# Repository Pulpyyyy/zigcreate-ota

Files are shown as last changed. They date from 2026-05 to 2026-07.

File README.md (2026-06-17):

# ZigCreate OTA — Bridge Zigbee pour ventilateur de plafond

Transformez votre ventilateur Tuya en appareil Zigbee natif, pilotable depuis votre box domotique favorite.

---

## Ce que vous pouvez contrôler

| Fonction | Contrôles disponibles |
|---|---|
| **Ventilateur** | Marche/arrêt · 6 niveaux de vitesse |
| **Lumière** | Marche/arrêt · Température de couleur en **cycle** (cran suivant : Froid→Neutre→Chaud→…) |
| **Minuterie** | Préréglages `1h` / `2h` / `4h` · Décompte visible en temps réel · Réinitialisation automatique à `off` en fin de décompte |
| **Son** | Activation / désactivation du bip de confirmation |
| **Direction** | Mode Été (brassage vers le bas) · Mode Hiver (remontée d'air chaud) |
| **Comportement après coupure** | État de la lumière et du son configurables (éteint / allumé / bascule / restauration) |
| **Température / Humidité** | Lecture de la température et de l'humidité ambiante — nécessite un capteur DHT11/DHT22 (optionnel, voir [câblage](wiring/WIRING.md#capteur-de-température--humidité-optionnel)) |

---

## Fonctionnalités

### Contrôle complet depuis l'interface domotique

Toutes les commandes sont disponibles depuis Zigbee2MQTT ou toute box compatible Zigbee :

- **Ventilateur** — marche/arrêt indépendant de la vitesse ; la vitesse peut être réglée de 1 à 6 sans éteindre le ventilateur. La dernière vitesse est mémorisée et restaurée à la prochaine mise en marche.
- **Lumière** — marche/arrêt avec mémorisation de l'état. **Température de couleur : cycle uniquement** — le matériel ne permet pas de choisir une couleur absolue, on ne peut qu'avancer d'un cran (Froid→Neutre→Chaud→…) comme avec la télécommande. La valeur remontée par le MCU est découplée de la couleur réelle, donc aucun état couleur fiable n'est exposé.
- **Minuterie** — déclenche l'extinction automatique après 1 h, 2 h ou 4 h. Le décompte restant (en minutes) est visible en temps réel dans l'interface. Le préréglage repasse automatiquement à `off` lorsque le décompte atteint zéro.
- **Son (bip)** — active ou désactive le bip sonore émis par l'appareil lors de chaque commande.
- **Direction** — inverse le sens de rotation du ventilateur pour le mode Hiver.

### Synchronisation en temps réel

Utiliser la télécommande physique (vitesse, on/off, direction…) met à jour l'état dans l'interface domotique instantanément. L'état est également resynchronisé automatiquement à chaque redémarrage du module.

### Comportement après coupure de courant

Il est possible de définir ce que fait chaque appareil au redémarrage après une coupure de courant. Ce réglage est disponible séparément pour la **lumière** et le **son** :

| Valeur | Comportement |
|---|---|
| `off` | Toujours éteint au démarrage |
| `on` | Toujours allumé au démarrage |
| `toggle` | Inverse l'état précédent |
| `previous` (défaut lumière) | Restaure l'état avant la coupure |

La température de couleur n'est PAS restaurée (cycle uniquement / découplée — voir ci-dessus). Par défaut, le bip démarre toujours désactivé.

### Mises à jour sans fil (OTA)

Le firmware se met à jour par liaison radio depuis Zigbee2MQTT, sans démontage ni câble. Les mises à jour sont proposées automatiquement dès qu'une nouvelle version est disponible dans l'index OTA de ce dépôt.

### Rôle routeur Zigbee

Le module fonctionne en tant que **routeur Zigbee** : il peut relayer les communications d'autres appareils Zigbee du réseau, contribuant ainsi à améliorer la portée et la robustesse du maillage.

### Indicateur LED

La LED RGB intégrée indique l'état du module en temps réel :

| Couleur / comportement | Signification |
|---|---|
| 🟠 Orange (ramping) | Démarrage en cours |
| 🔵 Cyan clignotant (0,5 s) | Recherche d'un réseau Zigbee (appairage) |
| 🟢 3 flashes verts | Appairage réussi |
| 🔴 Rouge clignotant rapide | Échec de connexion, nouvelle tentative |
| 🟡 Ambre (1 s on / 2 s off) | Mode dégradé — MU ventilateur injoignable |
| 🟠 Orange clignotant | Réinitialisation en attente (bouton maintenu) |
| ⚫ Éteinte | Fonctionnement normal |

### Réinitialisation

- **Bouton BOOT (5 s)** — maintenir le bouton BOOT appuyé 5 secondes remet l'appareil en configuration d'usine : effacement du réseau Zigbee mémorisé, des préférences et de l'historique de diagnostics. L'appareil redémarre ensuite en mode appairage.
- **GPIO externe** — un signal bas sur le GPIO de reset externe provoque un redémarrage simple (sans effacement). Consultez le [guide de câblage](wiring/WIRING.md).

### Récupération automatique

Si la connexion Zigbee échoue 3 fois de suite au démarrage, le module efface automatiquement sa configuration réseau corrompue et redémarre proprement.

Si le ventilateur ne répond plus pendant 15 secondes, le module passe en mode dégradé (LED ambre) : les commandes sont suspendues jusqu'au rétablissement de la communication, puis le fonctionnement reprend automatiquement.

---

## Câblage

Consultez le guide de câblage pour connaître les GPIOs à connecter selon votre carte :

- [Pinout Waveshare ESP32-H2-Zero](wiring/WIRING.md#waveshare-esp32-h2-zero)

---

## Installation dans Zigbee2MQTT

Le converter externe expose toutes les entités de l'appareil dans Z2M : ventilateur, lumière, minuterie, bip, direction, température de couleur, et capteurs de température / humidité.

**[→ Guide d'installation Z2M complet](../external_converters/README.md)**

---

## Installation dans ZHA (Home Assistant)

Le quirk custom permet à ZHA de reconnaître l'appareil et d'exposer les entités natives Home Assistant.

**[→ Guide d'installation ZHA complet](../zha_quirks/README.md)**

---

## Dépannage

En cas de problème en fonctionnement (LED ambre, commandes sans effet, bootloop, capteur DHT muet…), consultez le guide dédié :

**[→ Guide de dépannage](TROUBLESHOOTING.md)**

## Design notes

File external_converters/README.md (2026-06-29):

# Installation du converter Zigbee2MQTT

> Un **converter** est un fichier qui indique à Zigbee2MQTT comment communiquer avec l'appareil et quelles entités exposer.

---

## 1. Copier le converter

L'emplacement du dossier `external_converters/` dépend de votre installation Z2M :

| Installation | Chemin |
|---|---|
| **Add-on HA** | même dossier que `configuration.yaml` (ex. `/config/zigbee2mqtt/external_converters/`) |
| **LXC / Docker** | `data/external_converters/` dans le répertoire de données Z2M |

Créez le dossier s'il n'existe pas et copiez-y `create_wind_calm.mjs`.

---

## 2. Déclarer le converter

### Option A — via l'interface Z2M

Dans Z2M → **Paramètres** → **External converters**, ajoutez `create_wind_calm.mjs` directement depuis l'UI.

### Option B — via `configuration.yaml`

Ajoutez dans `configuration.yaml` :

```yaml
advanced:
  enable_external_js: true

external_converters:
  - create_wind_calm.mjs
```

Redémarrez Zigbee2MQTT. L'appareil **WIND-CALM (CREATE)** sera reconnu automatiquement lors du prochain appairage.

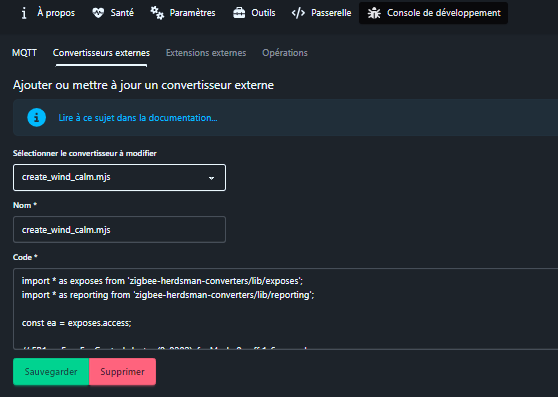
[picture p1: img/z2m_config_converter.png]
Converter déclaré dans configuration.yaml


---

## 3. Ajouter l'icône de l'appareil

Copiez le fichier `device_icons/windcalm.png` dans le dossier `images/devices/` au même niveau que `configuration.yaml` (créez le dossier s'il n'existe pas).

Ajoutez ensuite l'entrée dans votre `configuration.yaml` :

```yaml
devices:
  '0x<ieee_address>':
    friendly_name: wind_calm
    icon: 'images/devices/windcalm.png'
```

> Remplacez `0x<ieee_address>` par l'adresse IEEE réelle de votre appareil, visible dans l'interface Zigbee2MQTT après appairage.

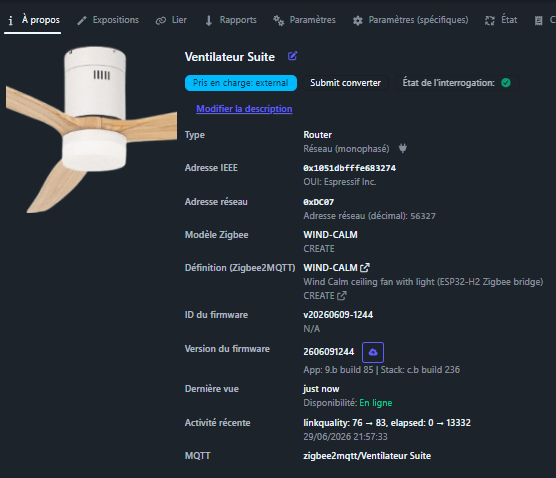
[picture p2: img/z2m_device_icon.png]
Appareil avec icône dans la liste des appareils Z2M


---

## 4. Activer les mises à jour OTA

```yaml
ota:
  zigbee_ota_override_index_location: https://raw.githubusercontent.com/Pulpyyyy/zigcreate-ota/main/ota/index.json
```

Redémarrez Zigbee2MQTT. Les mises à jour firmware seront proposées automatiquement.

Mise à jour OTA disponible dans Z2M

---

## 5. Appairer l'appareil

Activez le mode appairage dans Zigbee2MQTT, puis mettez le module sous tension (ou maintenez BOOT 5 s pour réinitialiser).

La LED clignote en **cyan** pendant la recherche de réseau, puis effectue **3 flashes verts** à la réussite.

---

## Entités disponibles

| Entité | Type | Description |
|---|---|---|
| `fan` | Interrupteur | Marche / arrêt du ventilateur |
| `fan_mode` | Liste | Vitesse du ventilateur (1 à 6) |
| `light` | Interrupteur | Marche / arrêt de la lumière |
| `color_step` | Interrupteur momentané | Température de couleur — **cycle uniquement** : passer sur **ON** avance d'un cran (froid→neutre→chaud→…) puis revient à **OFF** automatiquement. Cette ampoule ne permet PAS de choisir une couleur absolue, et il n'y a pas d'état couleur fiable. |
| `timer_preset` | Liste | Minuterie : `off` / `1h` / `2h` / `4h` |
| `timer_countdown` | Capteur | Décompte restant en minutes (lecture seule) |
| `beep` | Interrupteur | Bip sonore actif / silencieux |
| `direction` | Liste | Sens de rotation : `forward` (été) / `reverse` (hiver) |
| `power_on_behavior_light` | Liste | Comportement lumière après coupure |
| `power_on_behavior_beep` | Liste | Comportement bip après coupure |
| `temperature` | Capteur | Température ambiante (°C) — **désactivée par défaut** · requiert un capteur DHT11/DHT22 |
| `humidity` | Capteur | Humidité relative (%) — **désactivée par défaut** · requiert un capteur DHT11/DHT22 |
| `debug_firmware` | Interrupteur (config) | Bascule OTA du firmware : `ON` = build debug, `OFF` = build release. L'appareil persiste le choix, redémarre et télécharge l'image du canal correspondant. Outil de maintenance/dev. |

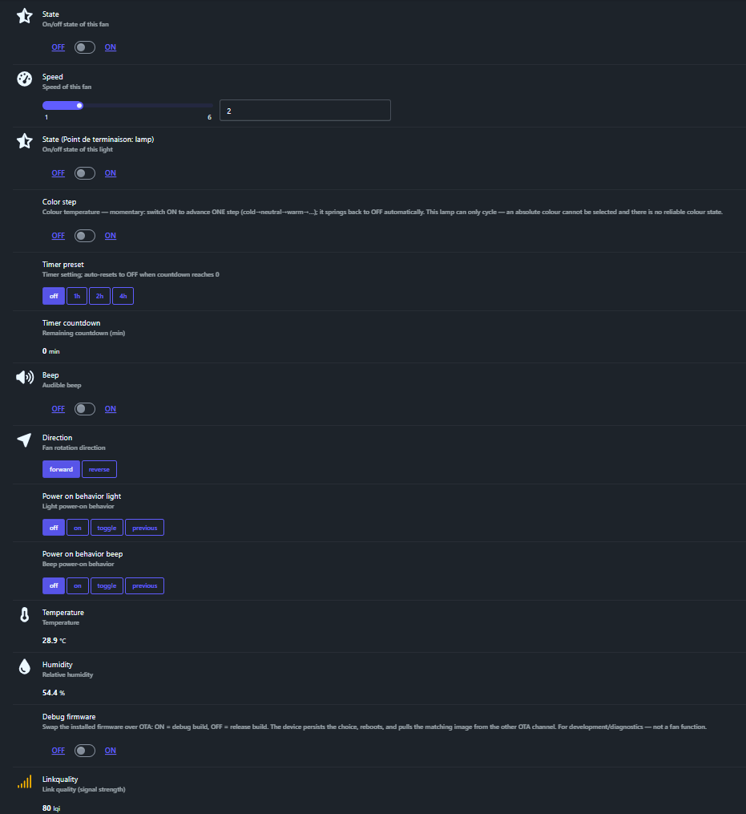
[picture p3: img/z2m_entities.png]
Toutes les entités dans l'interface Z2M


> Les entités `temperature` et `humidity` nécessitent un capteur DHT11/DHT22 câblé sur le module (voir [câblage](../docs/wiring/WIRING.md#capteur-de-température--humidité-optionnel)).
>
> L'interrupteur `debug_firmware` permet de passer un appareil déployé du firmware release au firmware debug (et inversement) **entièrement par OTA**, sans repasser par l'USB. Les deux canaux (release / debug) sont publiés automatiquement par la CI ; basculer l'interrupteur fait que l'appareil réclame l'image de l'autre canal au prochain cycle OTA.

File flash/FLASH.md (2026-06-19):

# Flasher le ZigCreate (ESP32-H2) via navigateur

Ce guide explique comment flasher le firmware **ZigCreate** sur une carte ESP32-H2 en utilisant l'outil en ligne **esptool-js**, sans installer de logiciel.

---

## Prérequis

- **Navigateur** : Google Chrome ou Microsoft Edge (WebSerial requis — Firefox non supporté)
- **Câble** : USB-C (données, pas uniquement charge)
- **Drivers** : Si votre carte utilise un chip USB-UART (CP2102, CH340…), installez le driver correspondant. Les cartes avec USB natif ESP32-H2 (ex : Waveshare ESP32-H2-Zero) n'en ont pas besoin.

---

## 1. Télécharger les binaires

Rendez-vous sur la dernière release du dépôt OTA :

> **https://github.com/Pulpyyyy/zigcreate-ota/releases/latest**

Téléchargez ces quatre fichiers :

| Fichier | Rôle |
|---|---|
| `bootloader.bin` | Bootloader ESP32-H2 |
| `partition-table.bin` | Table de partitions |
| `ota_data_initial.bin` | Indique au bootloader la partition à démarrer (optionnel, utilisé pour debug OTA)|
| `zigcreate.bin` | Firmware applicatif |

> `zigcreate.ota` est réservé aux mises à jour Zigbee over-the-air — **ne pas utiliser ici**.

---

## 2. Passer l'ESP32-H2 en mode téléchargement (Download Mode)

1. Maintenez le bouton **BOOT** (GPIO9) enfoncé
2. Appuyez brièvement sur **RESET** (bouton EN ou broche EN à la masse), puis relâchez-le
3. Relâchez le bouton **BOOT**

La carte est maintenant en mode téléchargement et attend un flash.

> Sur certaines cartes sans bouton dédié, le mode download s'active en maintenant GPIO9 à la masse au démarrage.

---

## 3. Flasher avec esptool-js

### 3.1 Ouvrir l'outil

Accédez à : **https://espressif.github.io/esptool-js/**

### 3.2 Se connecter

1. Cliquez sur **Connect**
2. Sélectionnez le port série correspondant à votre carte (ex : `COM3`, `COM8`, `/dev/ttyUSB0`)
3. Cliquez sur **Connect** dans la boîte de dialogue du navigateur

### 3.3 Configurer le flash

Dans la section **Flash Address**, renseignez les quatre fichiers avec leurs adresses exactes :

| Fichier | Adresse flash |
|---|---|
| `bootloader.bin` | `0x0` |
| `partition-table.bin` | `0x8000` |
| `ota_data_initial.bin` | `0x10000` |
| `zigcreate.bin` | `0x30000` |

Pour ajouter un fichier supplémentaire, cliquez sur **Add File**.

> Ces adresses correspondent à la table de partitions du projet. Ne pas les modifier.

### 3.4 Paramètres

| Paramètre | Valeur |
|---|---|
| Flash mode | `keep` |
| Flash frequency | `keep` |
| Flash size | `keep` |

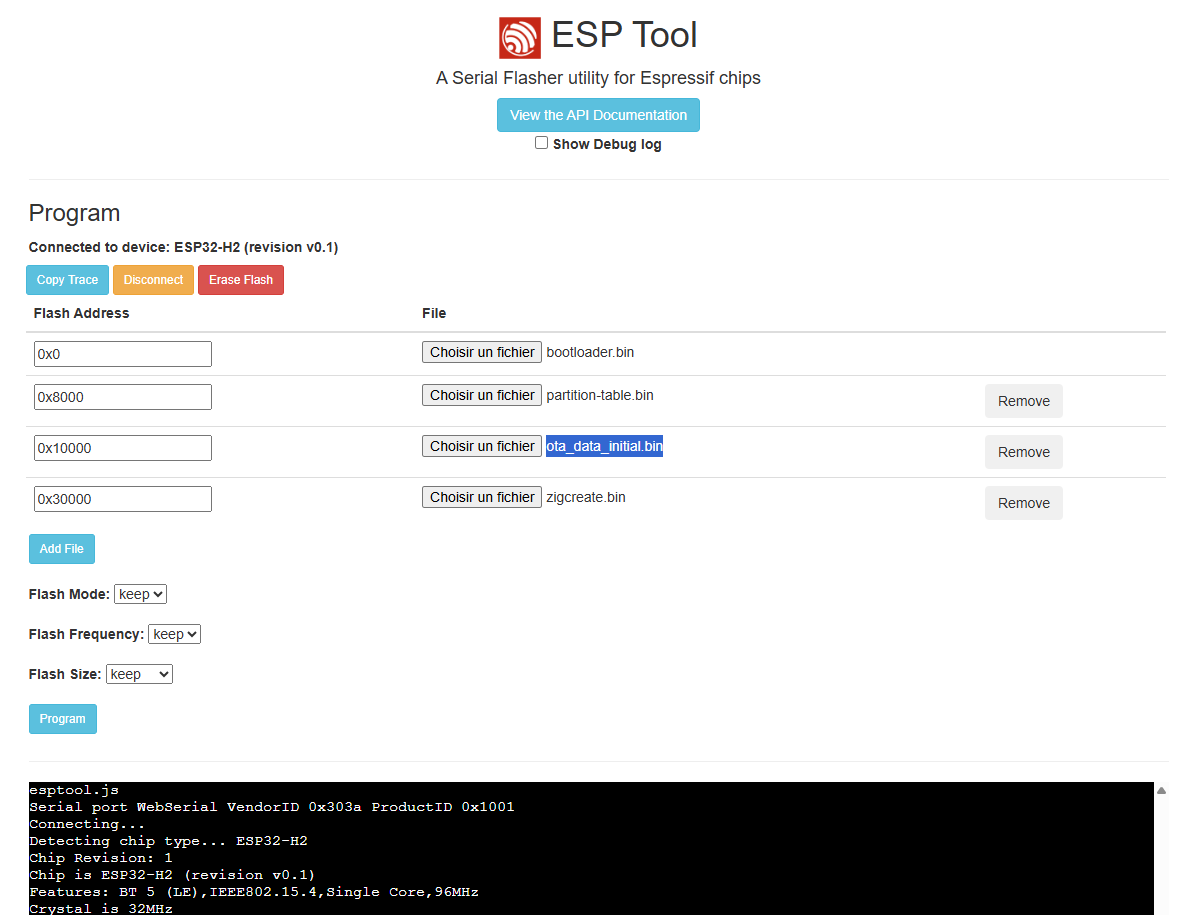
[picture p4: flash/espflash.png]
Configuration esptool-js


### 3.5 Lancer le flash

1. Cliquez sur **Program**
2. Attendez la fin du processus (la progression s'affiche dans la console)
3. Le message `Leaving... Hard resetting via RTS pin...` indique que le flash est terminé avec succès

---

## 4. Vérification

Après le flash, la carte redémarre automatiquement. La séquence LED normale est :

1. **Orange** (quelques secondes) — initialisation du module
2. **Cyan clignotant** — le module cherche un réseau Zigbee (appairage en cours)

> Le cyan clignotant est normal si aucun coordinateur Zigbee n'est à portée. L'appairage se fait depuis votre box domotique.

Si la carte ne redémarre pas, appuyez manuellement sur **RESET** (bouton EN ou broche EN à la masse brièvement).

---

## Résumé des adresses

```
0x00000  bootloader.bin
0x08000  partition-table.bin
0x10000  ota_data_initial.bin
0x30000  zigcreate.bin
```

---

## Dépannage

| Problème | Solution |
|---|---|
| Port non visible dans le navigateur | Vérifier le driver USB-UART, essayer un autre câble |
| Erreur de connexion | Recommencer la procédure mode téléchargement (étape 2) |
| La carte ne démarre pas après flash | Vérifier que les quatre fichiers sont bien flashés aux bonnes adresses |
| `Failed to connect` | S'assurer qu'aucun autre programme (moniteur série, IDE) n'occupe le port |

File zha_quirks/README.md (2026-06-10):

# Installation du quirk ZHA (Home Assistant)

> **ZHA** est l'intégration Zigbee native de Home Assistant.
> Un **quirk** est un fichier de personnalisation qui permet à ZHA de reconnaître correctement un appareil non standard. C'est l'équivalent du converter pour Zigbee2MQTT.

---

## 1. Copier le quirk

Copiez le fichier `create_wind_calm.py` dans le dossier `/config/custom_zha_quirks/` de votre installation Home Assistant (créez le dossier s'il n'existe pas).

```
config/
└── custom_zha_quirks/
    └── create_wind_calm.py
```

Quirk copié dans le dossier custom_zha_quirks via l'éditeur de fichiers HA

---

## 2. Déclarer le dossier de quirks dans configuration.yaml

```yaml
zha:
  custom_quirks_path: /config/custom_zha_quirks
```

Entrée zha dans configuration.yaml

---

## 3. Réappairer l'appareil

Redémarrez Home Assistant, puis réappairez l'appareil **WIND-CALM (CREATE)**.

Activez le mode appairage ZHA depuis **Paramètres → Appareils et services → ZHA → Ajouter un appareil**, puis mettez le module sous tension (ou maintenez BOOT 5 s pour réinitialiser).

La LED clignote en **cyan** pendant la recherche de réseau, puis effectue **3 flashes verts** à la réussite.

Appareil WIND-CALM reconnu lors de l'appairage ZHA

---

## Entités disponibles

| Fonction | Type d'entité HA | Description |
|---|---|---|
| Ventilateur | Ventilateur natif | Marche/arrêt + vitesse 1 à 6 |
| Lumière | Lumière | Marche/arrêt |
| Couleur (`color_step`) | Bouton | Température de couleur — **cycle uniquement** : chaque appui avance d'un cran (Froid→Neutre→Chaud→…). Pas de choix absolu possible. |
| Minuterie | — | Pas d'entité ZHA native — disponible uniquement via Zigbee2MQTT |
| Bip sonore | Interrupteur | Activation / désactivation du bip |
| Direction | Interrupteur | Éteint = été (brassage vers le bas) · Allumé = hiver (remontée d'air) |
| Température | Capteur | Température ambiante (°C) — requiert un capteur DHT11/DHT22 |
| Humidité | Capteur | Humidité relative (%) — requiert un capteur DHT11/DHT22 |
| Firmware debug | Interrupteur | Bascule OTA release ⇄ debug (Éteint = release, Allumé = debug) ; l'appareil redémarre et télécharge l'image correspondante. Maintenance/dev. |

Page de l'appareil dans Home Assistant avec toutes ses entités

---

## Limitations vs Zigbee2MQTT

- **Température de couleur** : **cycle uniquement.** Le matériel ne permet PAS de choisir une couleur absolue — le MCU ne fait que cycler la couleur par paliers (Froid→Neutre→Chaud→…), comme la télécommande, et la valeur qu'il remonte est découplée de la couleur réelle. L'entité `color_step` est donc un simple **bouton** « cran suivant » (chaque appui = un cran), sans état fiable.
- **Minuterie** : non accessible directement dans ZHA. Pour l'utiliser, passez par **Zigbee2MQTT** ou créez une automatisation HA avancée via le service `zha.issue_zigbee_cluster_command`.
- **Mises à jour OTA** : les mises à jour sans fil via ZHA ne sont pas supportées. Utilisez Zigbee2MQTT pour les OTA.

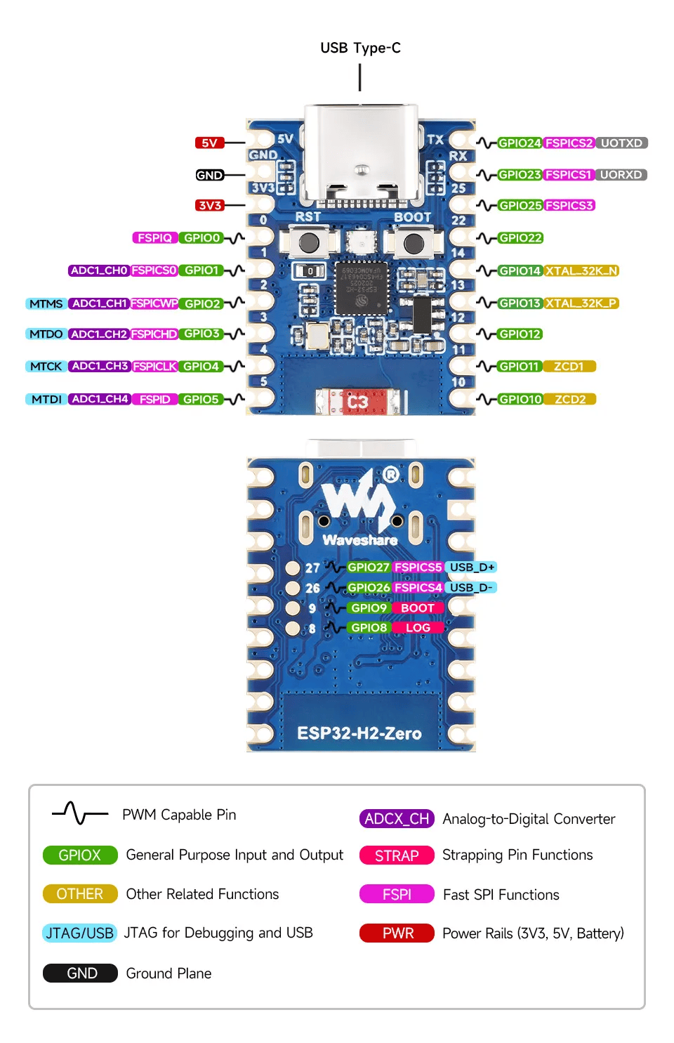
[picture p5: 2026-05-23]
pcb/H2 zero/pinout top bottom.png

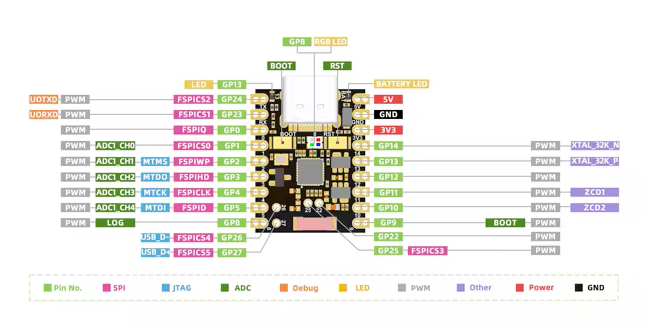
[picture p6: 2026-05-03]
pcb/H2 supermini/ESP32 pinout.png

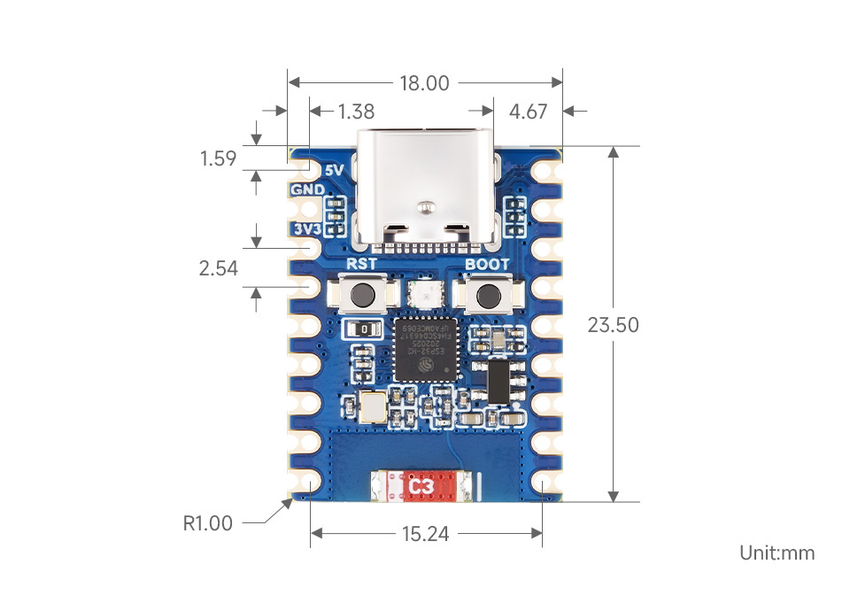
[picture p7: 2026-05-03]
pcb/H2 supermini/ESP32 size.jpg

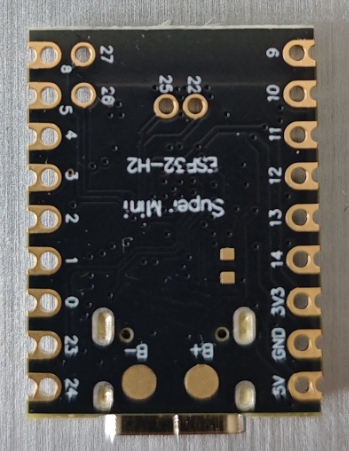
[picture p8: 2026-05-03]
pcb/H2 supermini/dessous.jpg

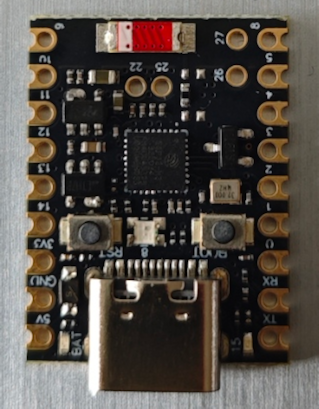
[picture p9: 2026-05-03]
pcb/H2 supermini/dessus.png

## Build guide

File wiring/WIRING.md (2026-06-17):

# Câblage ZigCreate — Pinout par carte

Ce guide décrit les connexions à réaliser entre l'ESP32-H2 et le MCU Tuya du ventilateur, selon la carte utilisée.

---

## Alimentation — point critique

Le MCU Tuya expose une sortie **3,3 V** qui sert à alimenter l'ESP32-H2-Zero via sa broche **3V3**. Ne jamais alimenter l'ESP32-H2 simultanément via USB et via cette broche — risque de conflit d'alimentation.

> **Carte recommandée : Waveshare ESP32-H2-Zero.** Alimentée en 3,3 V depuis le MCU Tuya, elle fonctionne de façon stable.
>
> ⚠️ **L'ESP32-H2 Super Mini est à éviter** : son régulateur interne provoque un *bootloop* (redémarrages en boucle) lors de l'alimentation directe, malgré l'ajout de condensateurs de découplage (10 µF à 470 µF testés). Cette piste a été abandonnée.

---

## Connexions à réaliser (toutes cartes)

| Signal | De | Vers | Remarque |
|---|---|---|---|
| VCC | MCU Tuya — 3,3 V | ESP32-H2 — broche **3V3** | Alimentation directe |
| GND | MCU Tuya — GND | ESP32-H2 — GND | Masse commune obligatoire |
| TX | ESP32-H2 — GPIO TX | MCU Tuya — RX | |
| RX | MCU Tuya — TX | ESP32-H2 — GPIO RX | |

> La liaison UART fonctionne en **8N1 à 9600 baud**. TX de l'ESP32 → RX du MCU Tuya, et inversement.

---

## Waveshare ESP32-H2-Zero

```
En-têtes de la carte (vue de dessus, USB-C en haut) :

En-tête gauche (haut → bas)   En-tête droit (haut → bas)
  5V                              24 (TX)
  GND  ─── Masse commune         23 (RX)
  3V3  ◄── VCC depuis MCU         25
  0                              22
  1                              14
  2    ◄── EXT_RESET             13
  3    ◄── DHTxx DATA             12
  4    ──► TUYA TX               11
  5    ◄── TUYA RX               10
```

| Fonction | GPIO | Broche en-tête | Remarque |
|---|---|---|---|
| UART TX → MCU Tuya RX | GPIO4 | En-tête gauche, 8e | |
| UART RX ← MCU Tuya TX | GPIO5 | En-tête gauche, 9e | |
| Alimentation entrée | — | En-tête gauche, 3e (**3V3**) | Depuis le 3,3 V du MCU Tuya |
| Masse | — | En-tête gauche, 2e (**GND**) | Commune avec MCU Tuya |
| LED RGB (WS2812) | GPIO8 | Pad LOG (castellé) | Interne, ne pas câbler |
| Bouton BOOT / Reset Zigbee | GPIO9 | Pad castellé bas | En fonctionnement normal : maintenir 5 s pour reset usine. Pour le flash : voir [FLASH.md](../flash/FLASH.md) |
| Reset externe (actif bas) | GPIO2 | En-tête gauche, 6e | Redémarrage software |
| Capteur T°/HR DATA (optionnel) | GPIO3 | En-tête gauche, 7e | Voir section [Capteur T°/HR](#capteur-de-température--humidité-optionnel) |
| USB D+ | GPIO27 | Pad castellé bas | Réservé USB, ne pas utiliser |
| USB D- | GPIO26 | Pad castellé bas | Réservé USB, ne pas utiliser |

### Schéma de câblage

```
Waveshare ESP32-H2-Zero          MCU Tuya
┌──────────────────┐            ┌──────────┐
│  3V3         ◄───┼────────────│ 3V3      │
│  GND         ────┼────────────│ GND      │
│  GPIO4  (TX) ────┼────────────│ RX       │
│  GPIO5  (RX) ◄───┼────────────│ TX       │
│  GPIO2 (RST) ◄───┼────────────│ EN       │
└──────────────────┘            └──────────┘
```

### Photos du câblage

ESP32-H2-Zero avec les connecteurs Dupont :

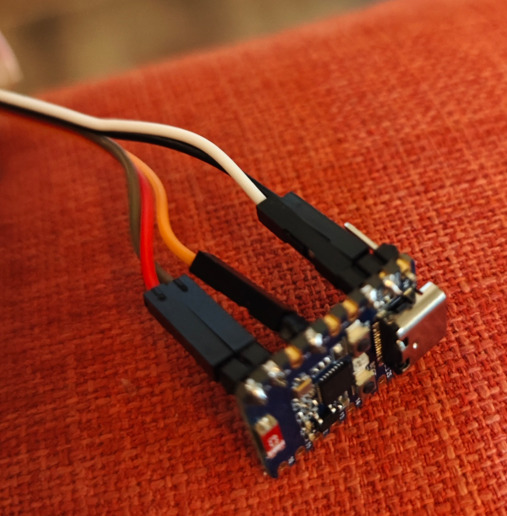
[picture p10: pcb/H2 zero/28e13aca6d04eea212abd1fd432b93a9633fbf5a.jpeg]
ESP32-H2-Zero câblé


MCU Tuya côté ventilateur :

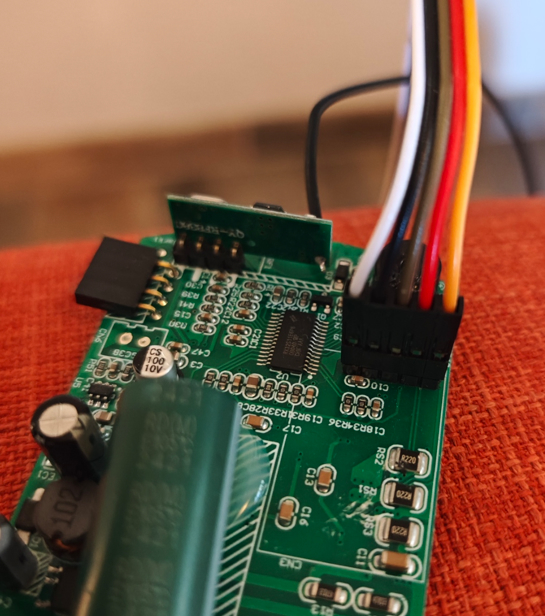
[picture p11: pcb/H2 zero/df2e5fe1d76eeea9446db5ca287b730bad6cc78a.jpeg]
MCU Tuya câblé


---

## Préparation & test à blanc avant soudure définitive

> **Toujours valider en Dupont/USB avant de souder en permanence.** Une fois la carte soudée dans le plafonnier, reprendre un TX/RX inversé devient pénible. Le câblage Dupont (photos ci-dessus) sert précisément à cette phase de validation.

1. **Flasher + appairer la carte d'abord sur USB**, hors ventilateur. Vérifier la séquence LED orange → cyan clignotant → 3 flashes verts, et que l'appareil apparaît dans Zigbee2MQTT / ZHA. → firmware et radio validés avant tout câblage.
2. **Repérer les 4 points sur le MCU Tuya** : 3,3 V, GND, MCU-TX, MCU-RX.
3. **Câbler en Dupont** : 3V3↔3V3, GND↔GND, **ESP TX (GPIO4) → MCU RX**, **MCU TX → ESP RX (GPIO5)**. L'inversion TX/RX est l'erreur la plus fréquente.
4. **Ne jamais alimenter en USB *et* en 3,3 V simultanément.** Pour ce test : soit USB seul, soit 3,3 V du MCU seul.
5. **Test fonctionnel complet en Dupont** : ventilateur (6 vitesses), lumière, cycle de couleur, minuterie, direction, bip — et la **synchro télécommande** (agir sur la télécommande physique doit mettre à jour l'état dans l'interface). Si la LED passe **ambre**, le MCU ne répond pas → voir le [guide de dépannage](../TROUBLESHOOTING.md).
6. **Capteur DHT (optionnel)** : vérifier que température et humidité remontent **avant** de souder. Alimentation **3,3 V** (jamais 5 V).
7. **Vérifier l'orientation de la carte et le dégagement de l'antenne** dans le boîtier avant de figer : l'antenne Zigbee ne doit pas être plaquée contre une masse métallique.
8. **Souder définitivement** une fois tout validé, puis effectuer un dernier test fonctionnel.

---

## Reset externe (optionnel)

Un niveau bas (GND) bref sur ce GPIO provoque un redémarrage software, sans effacer le réseau Zigbee ni les préférences.

| Carte | GPIO | Broche en-tête |
|---|---|---|
| ESP32-H2-Zero | GPIO2 | En-tête gauche, 6e |

> Pour un reset usine complet (effacement réseau + préférences), utiliser le bouton BOOT maintenu **5 secondes**.

---

## Capteur de température / humidité (optionnel)

Le firmware intègre la prise en charge d'un capteur **DHT22** ou **DHT11** pour reporter la température et l'humidité ambiantes via Zigbee. Ce capteur est **entièrement optionnel** : sans lui, toutes les autres fonctions restent opérationnelles.

> **DHT11 ou DHT22 ?** Le câblage est identique (même protocole 1 fil) et le firmware **détecte automatiquement** le capteur branché (DHT22, DHT11 ou aucun) — rien à configurer. Au démarrage il sonde les deux familles et verrouille celle qui répond ; si aucun capteur n'est présent, la tâche se contente d'avertir sans perturber le reste. Le DHT22 est plus précis et couvre les températures négatives ; le DHT11 est moins cher mais limité (0–50 °C, ±2 °C, ±5 % HR, résolution 1°).

### Module PCB recommandé

> Utiliser de préférence un **module sur PCB** (3 broches : VCC, DATA, GND). Ces modules intègrent la résistance de pull-up et le condensateur de découplage — aucun composant externe à ajouter.
>
> Le capteur nu (4 broches) nécessite l'ajout d'une résistance de 4,7 kΩ à 10 kΩ entre VCC et DATA, et d'un condensateur 100 nF entre VCC et GND.

Module DHT22 sur PCB (3 broches) tout intégré, câble direct :

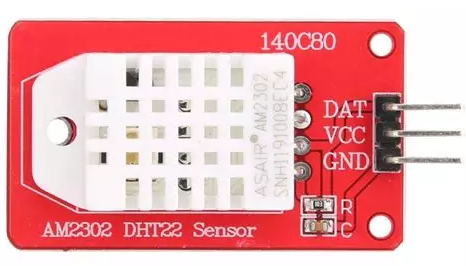
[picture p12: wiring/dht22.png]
Module DHT22 sur PCB


### Connexions

| Signal | Module capteur | ESP32-H2 | Remarque |
|---|---|---|---|
| VCC | VCC | **3,3 V** | Ne pas alimenter en 5 V |
| GND | GND | GND | Masse commune |
| DATA | DATA | GPIO selon carte | Voir tableau ci-dessous |

| Carte | GPIO DATA capteur | Broche en-tête |
|---|---|---|
| ESP32-H2-Zero | GPIO3 | En-tête gauche, 7e |

### Entités Zigbee générées

Une fois câblé, le firmware reporte automatiquement la température et l'humidité toutes les 60 secondes :

| Entité | Cluster ZCL | Précision |
|---|---|---|
| `temperature` | TemperatureMeasurement (0x0402) | 0,1 °C |
| `humidity` | RelativeHumidity (0x0405) | 0,1 % |

> Sous **Zigbee2MQTT**, ces entités sont **désactivées par défaut** — les activer manuellement dans l'interface HA si souhaité.
> Sous **ZHA**, les entités température et humidité sont créées actives.

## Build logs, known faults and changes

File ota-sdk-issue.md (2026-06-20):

# [Bug] OTA Upgrade client silently resets the download to FileOffset=0 on a single ImageBlockResponse timeout (no block retry, no ABORT callback)

## Environment

| | |
|---|---|
| **esp-zigbee-lib** | `2.0.1` (dependency `espressif/esp-zigbee-lib: ~2.0.0`) |
| **ESP-IDF** | `v6.0.1` |
| **Chip** | ESP32-H2 (rev v1.2), native 802.15.4 radio |
| **Device role** | Router, ZCL OTA Upgrade **client** (cluster 0x0019) |
| **OTA coordinator/server** | Zigbee2MQTT (zigbee-herdsman 10.4.0) |
| **Requested block size** | 255 B via `ezb_zcl_ota_upgrade_set_download_block_size(ep, 255)` |
| **Actual ImageBlockResponse size from server** | ~50 B (one unfragmented secured 802.15.4 frame) |
| **Image size** | ~591 KB → ~11 800 blocks of 50 B |

## Summary

During a ZCL OTA download, if **one** `ImageBlockResponse` is lost/late, the OTA client's
response timeout fires (~7 s) and the client **silently resets the whole session**:
`FileOffset` → `0` and `ImageUpgradeStatus` → `0x00` (NORMAL). It does **not**:

1. retry the `ImageBlockRequest` for the current offset, and
2. notify the application via the progress callback (no `..._PROGRESS_ABORT`).

The client then stays idle and never issues another `ImageBlockRequest`, so the server
(Z2M) times out after 150 s ("device did not start/finish firmware download"). Because the
download restarts from scratch every time, and a ~591 KB image is ~11 800 tiny (50 B) blocks,
the probability of completing without a single lost block is effectively zero — the OTA
**never completes** on a real-world link.

## Steps to reproduce

1. ESP32-H2 router as OTA client, esp-zigbee-lib 2.0.1.
2. Z2M as OTA server, offer an image (~591 KB).
3. Start the OTA. The download progresses normally at ~50 B/block.
4. Wait for any single block exchange to be lost (happens within a few thousand blocks).

## Expected behavior

On an `ImageBlockResponse` timeout, the client re-sends the `ImageBlockRequest` for the
**current** `FileOffset` (bounded number of retries), preserving download progress. If it
ultimately gives up, it invokes the application progress callback with `ABORT` so the app can
clean up.

## Actual behavior

The client discards all progress (`FileOffset` → 0, `ImageUpgradeStatus` → NORMAL), issues no
further requests, and gives no callback. The transfer is dead; only a brand-new
server-initiated session (ImageNotify) can restart it — from offset 0.

## Evidence

Application-side trace (we poll the client's own ZCL attributes every 10 s during the transfer
and timestamp the last RECEIVING callback):

```
OTA START — ver=0x9B5754CC size=591102 B
OTA block #1 raw=50 B file_off=0 (written 0 B)
...
OTA poll:  idle=63ms    block#107 written=5288B | FileOffset=5350 status=0x01   <- downloading
OTA poll:  idle=3062ms  block#135 written=6688B | FileOffset=6750 status=0x01   <- last block #135
OTA STALL: idle=13063ms block#135 written=6688B | FileOffset=0    status=0x00   <- client reset!
OTA STALL: idle=23064ms block#135 written=6688B | FileOffset=0    status=0x00
```

- `status` (ImageUpgradeStatus 0x0006): `0x01` (DOWNLOAD_IN_PROGRESS) → `0x00` (NORMAL).
- `FileOffset` (0x0001): `6750` → `0`.
- No `PROGRESS_ABORT` (or any) callback fires; the application still believes a transfer is active.
- The stall offset is random across runs (observed at 6.5 KB, 32 KB, 56 KB, 84 KB) — consistent
  with a probabilistic single-block loss rather than a fixed boundary.

The corresponding server side reports:
`Device <addr> did not start/finish firmware download after being notified.
(Timeout after 150000ms [clusterId=25 cmdId=3])` — i.e. it is waiting for the next
`ImageBlockRequest` (cmd 0x03) that never comes.

## What we ruled out

- **Rate negotiation / MinimumBlockPeriod**: not the cause (and the 0x0009 attribute is not even
  exposed to read on the client here).
- **Application handler**: our progress handler writes every block correctly up to the stall;
  it receives no further callbacks after the reset.
- **Memory**: free heap is stable (~150 KB) at the stall.
- **Link jitter**: cadence is steady (~50 B every ~190–250 ms) right up to the cliff, then a clean
  stop — a single dropped frame, not progressive degradation.

## Suggested fix

In the OTA client downloading state machine (the `ota_upgrade_downloading_rsp_timeout` path):

1. On `ImageBlockResponse` timeout, **re-send `ImageBlockRequest` at the current `FileOffset`**
   with a bounded retry count, instead of resetting `FileOffset`/`ImageUpgradeStatus`.
2. Only after exhausting retries, abort — and **invoke the application progress callback with
   `ABORT`** so the app can release its `esp_ota_handle`.

This makes the transfer resilient to the inevitable single-block loss over a ~11 800-block
download.

## Workaround (works) — userspace OTA client

**A full userspace re-implementation of the OTA client works and makes OTA complete reliably
on a lossy link.** Details + empirical proof are in
[this follow-up comment](https://github.com/espressif/esp-zigbee-sdk/issues/833#issuecomment-4756769933);
full single-file reference: https://gist.github.com/Pulpyyyy/0241f09c90e120ca654aa29bdc6ac1e3

In short:
- Register a raw ZCL handler and **consume every genOta (0x0019) frame** so the built-in client
  stays dormant.
- Drive the transfer from the app: send `QueryNextImageRequest` / `ImageBlockRequest` /
  `UpgradeEndRequest` via `ezb_zcl_custom_cmd_req()` (it accepts the standard cluster 0x19), and
  parse responses from `raw_frame->payload`.
- **On a block timeout, re-send the `ImageBlockRequest` at the same `FileOffset`** (bounded
  retries) — Z2M serves it statelessly, so the download resumes. Observed recovering from 7
  consecutive lost blocks at one offset and completing the full ~593 KB image.

This confirms the root cause and the expected fix (retry the block instead of resetting), but it
is a heavy app-side workaround — the proper fix belongs in the precompiled OTA client.

### Workarounds that do NOT work
- **App-driven resume without bypassing the built-in client**: seed the `FileOffset` attribute
  and re-send a `QueryNextImageRequest`. The seed sticks, but Z2M does not answer a device-initiated
  query mid-session (it waits for an `ImageBlockRequest`), and there's no public API to make the
  built-in client re-issue a block request → the resume can't be driven this way.
- **Bigger blocks (APS fragmentation)** reduce the block count (fewer loss opportunities) but don't
  fix the underlying no-retry behavior.

---

## Full annotated serial trace

> **Note on instrumentation.** The `OTA block #N … file_off=…`, `OTA poll: …` and
> `OTA STALL: …` lines are **application-added**, not SDK logs. A watchdog task polls the
> OTA client's own public ZCL attributes every 10 s and timestamps each RECEIVING callback:
> - `FileOffset` = attribute `0x0001`
> - `status` = `ImageUpgradeStatus` attribute `0x0006`
> - `minBlockPeriod` = attribute `0x0009` (`65535` = our "attribute not present" sentinel — it is
>   not exposed on the client, hence unreadable; `FileOffset`/`status` are conclusive on their own)
> - `block#` / `written` = our RECEIVING-callback counter and `esp_ota_write` byte count
>
> This is exactly how we observed the client's internal reset without any SDK trace (the
> precompiled libs expose no ZBOSS trace symbols).

### Boot + transfer start (client cur_ver 0x9B5754CB, image 0x9B5754CC, 591102 B)

```
I zigbee: OTA client: mfr=0x5096 type=0x50C5 cur_ver=0x9B5754CB max_data=255
I zigbee: OTA ImageNotify received → kicking QueryNextImageRequest
I zigbee: OTA query_next_image sent (type=0x50C5 ver=0x9B5754CB)
I zigbee: OTA query resp → image available ver=0x9B5754CC size=591102 B
I zigbee: OTA START — mfr=0x5096 type=0x50C5 ver=0x9B5754CC size=591102 B
I zigbee: OTA partition: ota_0 @ 0x000F0000 size=786432
I zigbee: OTA block #1 raw=50 B file_off=0   (written 0 B)
I zigbee: OTA block #2 raw=50 B file_off=50  (written 0 B)
I zigbee: OTA block #3 raw=50 B file_off=100 (written 38 B)
I zigbee: OTA block #4 raw=50 B file_off=150 (written 88 B)
I zigbee: OTA block #5 raw=50 B file_off=200 (written 138 B)
...
```
Every block is **50 B** (server caps the ImageBlockResponse to a single secured frame; the
client requested 255 B). 591 KB / 50 B ≈ **11 800 blocks**.

### Normal progress (FileOffset advancing, status=0x01 DOWNLOAD_IN_PROGRESS)

```
W zigbee: OTA poll:  idle=64ms   block#27  written=1288B | FileOffset=1350 status=0x01 minBlockPeriod=65535 | heap=153312B
W zigbee: OTA poll:  idle=60ms   block#67  written=3288B | FileOffset=3350 status=0x01 minBlockPeriod=65535 | heap=155324B
I zigbee: OTA received 4 KB (block #84)
W zigbee: OTA poll:  idle=63ms   block#107 written=5288B | FileOffset=5350 status=0x01 minBlockPeriod=65535 | heap=155360B
W zigbee: OTA poll:  idle=3062ms block#135 written=6688B | FileOffset=6750 status=0x01 minBlockPeriod=65535 | heap=155360B
```

### The bug: single block lost → client resets the whole session (no retry, no callback)

```
W zigbee: OTA STALL: idle=13063ms block#135 written=6688B | FileOffset=0 status=0x00 minBlockPeriod=65535 | heap=155360B
W zigbee: OTA STALL: idle=23064ms block#135 written=6688B | FileOffset=0 status=0x00 minBlockPeriod=65535 | heap=155360B
```
- Last RECEIVING callback was block #135 (`written=6688B`); no further callbacks.
- `FileOffset`: `6750` → `0`; `status`: `0x01` → `0x00` (NORMAL).
- No `PROGRESS_ABORT` (or any) callback — the application still thinks a transfer is active.
- Stall offset varies run-to-run (also seen at 32 KB, 56 KB, 84 KB) → probabilistic single-block loss.

### Application auto-resume attempt fails (server ignores a device-initiated re-query)

```
W zigbee: OTA auto-resume: seeded FileOffset=6750, re-querying
I zigbee: OTA query_next_image sent (type=0x50C5 ver=0x9B5754CB)
W zigbee: OTA STALL: idle=33077ms block#135 written=6688B | FileOffset=6750 status=0x00 ...   <- seed sticks, still idle
W zigbee: OTA STALL: idle=43078ms block#135 written=6688B | FileOffset=6750 status=0x00 ...
W zigbee: OTA auto-resume: seeded FileOffset=6750, re-querying
I zigbee: OTA query_next_image sent (type=0x50C5 ver=0x9B5754CB)
   (... no "OTA query resp" ever follows any re-query — Z2M does not answer a device-initiated
        QueryNextImageRequest while it is waiting for the next ImageBlockRequest ...)
```
Writing `FileOffset` back works (it reads back `6750`), but the client never re-enters the
download state and there is no API to make it re-issue an `ImageBlockRequest`.

### Server side (Zigbee2MQTT)

```
z2m: OTA update of '<device>' failed (Device <addr> did not start/finish firmware download
     after being notified. (Timeout after 150000ms [clusterId=25 cmdId=3]))
```
`cmdId=3` = the server is waiting for the next `ImageBlockRequest` from the client, which never
comes after the client's silent reset.

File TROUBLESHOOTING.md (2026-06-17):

# Dépannage ZigCreate

Ce guide couvre les problèmes rencontrés **en fonctionnement** (après flash et câblage). Pour les problèmes liés au flash USB, voir [FLASH.md § Dépannage](flash/FLASH.md#dépannage). Pour la préparation et le test à blanc avant soudure, voir [WIRING.md § Préparation & test à blanc](wiring/WIRING.md#préparation--test-à-blanc-avant-soudure-définitive).

---

## Comprendre la LED

La LED RGB intégrée est le premier outil de diagnostic. Rappel des états :

| Couleur / comportement | Signification |
|---|---|
| 🟠 Orange (ramping) | Démarrage en cours |
| 🔵 Cyan clignotant (0,5 s) | Recherche d'un réseau Zigbee (appairage) |
| 🟢 3 flashes verts | Appairage réussi |
| 🔴 Rouge clignotant rapide | Échec de connexion Zigbee, nouvelle tentative |
| 🟡 Ambre (1 s on / 2 s off) | Mode dégradé — MCU ventilateur injoignable |
| 🟠 Orange clignotant | Réinitialisation en attente (bouton BOOT maintenu) |
| ⚫ Éteinte | Fonctionnement normal |

---

## Tableau de dépannage

| Symptôme | Cause probable | Solution |
|---|---|---|
| 🟡 **LED ambre** (1 s on / 2 s off) | Le MCU est silencieux depuis **plus de 15 s** : TX/RX inversés, masse non commune, mauvaise soudure, ou baud ≠ 9600 | Vérifier que **TX et RX sont croisés** (ESP TX → MCU RX, MCU TX → ESP RX), la masse commune et les soudures. Le module repasse en fonctionnement normal dès que le MCU répond. |
| Commandes sans effet, LED éteinte | Liaison UART partiellement fonctionnelle (un seul fil en défaut) | Contrôler chaque fil UART individuellement |
| 🔴 **Rouge clignotant rapide** | Échec du *steering* Zigbee : coordinateur hors portée ou réseau saturé | Rapprocher le module du coordinateur, rouvrir le mode appairage côté box |
| 🔵 **Cyan en continu** | Aucun réseau trouvé (le module est en mode appairage) | Ouvrir l'appairage côté box ; vérifier le canal et la portée |
| **Redémarrages en boucle (bootloop)** | Carte **ESP32-H2 Super Mini** (régulateur de tension insuffisant) — piste abandonnée | Utiliser la **Waveshare ESP32-H2-Zero**, alimentée en **3,3 V** depuis le MCU |
| Reboot Zigbee spontané au démarrage | Récupération automatique : après 3 échecs de connexion consécutifs, le firmware efface le réseau corrompu et redémarre | Comportement normal — laisser le module réappairer |
| **DHT : pas de valeurs** | Résistance de pull-up absente (capteur nu), alimentation en 5 V, ou mauvais GPIO | Préférer un module 3 broches (pull-up intégrée), alimenter en **3,3 V**, DATA sur **GPIO3** (ESP32-H2-Zero) |
| Reset usine impossible | Bouton BOOT pas maintenu assez longtemps | Maintenir **BOOT 5 s** (GPIO9) — la LED passe orange clignotant pour confirmer le reset en attente |
| Carte ne démarre pas / instable | Conflit d'alimentation USB + 3,3 V simultanés | N'alimenter que par **une seule** source à la fois |

---

## Récupération automatique (intégrée au firmware)

- **Réseau Zigbee corrompu** : si la connexion échoue 3 fois de suite au démarrage, le module efface automatiquement sa configuration réseau et redémarre proprement.
- **Mode dégradé** : si le MCU du ventilateur ne répond plus pendant 15 s, le module passe en LED ambre et suspend les commandes ; le fonctionnement reprend automatiquement dès le rétablissement de la communication.

---

## Réinitialisation manuelle

- **Reset usine** (efface réseau Zigbee + préférences + diagnostics) : maintenir **BOOT 5 s**. Le module redémarre en mode appairage.
- **Redémarrage simple** (sans effacement) : signal bas bref sur le GPIO de reset externe (GPIO2 sur l'ESP32-H2-Zero). Voir [WIRING.md § Reset externe](wiring/WIRING.md#reset-externe-optionnel).

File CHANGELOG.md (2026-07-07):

# Changelog

Historique des évolutions du firmware. Chaque version correspond à une mise à jour
`vAAAAMMJJ-HHMM` (date et heure de build).

<!--
Note maintenance (dev) : remplir la section [Unreleased] ci-dessous en langage utilisateur.
La CI la publie comme notes de release et remplace "[Unreleased]" par le vrai numéro de
version (voir .github/workflows/build.yml). Ne pas éditer la copie du repo OTA : régénérée.
-->

## v20260707-2134

### Nouveautés
- **Mises à jour OTA fiables** : la mise à jour du firmware par Zigbee (sans fil) va
  désormais jusqu'au bout, même quand le signal radio est faible ou perturbé — plus besoin
  de démonter l'appareil pour le brancher en USB. Les versions précédentes sont à flasher via USB.

### Améliorations
- **Température / humidité un peu plus fiables** : les valeurs aberrantes dues aux parasites
  électriques (ventilateur, etc.) sont écartées automatiquement.

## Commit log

2026-05-02 chore: OTA index → v20260502-104427 [skip ci]
2026-05-02 chore: OTA index → v20260502-110745 [skip ci]
2026-05-02 chore: OTA index → v20260502-114633 [skip ci]
2026-05-02 chore: OTA index → v20260502-203431 [skip ci]
2026-05-02 chore: OTA index → v20260502-204144 [skip ci]
2026-05-02 chore: OTA index → v20260502-204938 [skip ci]
2026-05-02 chore: OTA index → v20260502-210423 [skip ci]
2026-05-03 pcb infos
    [h2_carrier.kicad_pcb, h2_carrier.kicad_sch]
2026-05-03 chore: OTA index → v20260503-182808 [skip ci]
2026-05-03 chore: OTA index → v20260503-190817 [skip ci]
2026-05-08 chore: OTA index → v20260508-141336 [skip ci]
2026-05-08 chore: OTA index → v20260508-144236 [skip ci]
2026-05-19 change defaut hardware to H2 zero
    [h2_carrier.kicad_pcb, h2_carrier.kicad_sch]
2026-05-19 chore: OTA index → v20260519-201632 [skip ci]
2026-05-19 chore: OTA index → v20260519-201631-debug [skip ci]
2026-05-20 chore: OTA index → v20260520-173216 [skip ci]
2026-05-24 chore: OTA index → v20260524-035615-debug [skip ci]
2026-05-24 chore: OTA index → v20260524-035614 [skip ci]
2026-05-25 add h2 zero pcb
2026-05-30 chore: OTA index → v20260530-100901-debug [skip ci]
2026-05-30 chore: OTA index → v20260530-140712-debug [skip ci]
2026-05-30 chore: OTA index → v20260530-140712 [skip ci]
2026-05-30 chore: OTA index → v20260530-184419-debug [skip ci]
2026-05-30 chore: OTA index → v20260530-184417 [skip ci]
2026-05-31 chore: OTA index → v20260531-153450-esp32h2_zero [skip ci]
2026-05-31 chore: OTA index → v20260531-153450-esp32h2_zero-debug [skip ci]
2026-06-05 chore: OTA index → v20260605-1720-esp32h2_zero [skip ci]
2026-06-05 chore: OTA index → v20260605-1720-esp32h2_zero-debug [skip ci]
2026-06-05 chore: OTA index → v20260605-1801-esp32h2_zero [skip ci]
2026-06-05 chore: OTA index → v20260605-1801-esp32h2_zero-debug [skip ci]
2026-06-06 chore: OTA index → v20260606-1404-esp32h2_zero [skip ci]
2026-06-06 chore: OTA index → v20260606-1404-esp32h2_zero-debug [skip ci]
2026-06-07 chore: OTA index → v20260607-1339-esp32h2_zero [skip ci]
2026-06-07 chore: OTA index → v20260607-1339-esp32h2_zero-debug [skip ci]
2026-06-07 chore: OTA index → v20260607-1914-esp32h2_zero [skip ci]
2026-06-07 chore: OTA index → v20260607-1914-esp32h2_zero-debug [skip ci]
2026-06-07 chore: OTA index → v20260607-2044-esp32h2_zero [skip ci]
2026-06-07 chore: OTA index → v20260607-2044-esp32h2_zero-debug [skip ci]
2026-06-08 chore: OTA index → v20260608-0816-esp32h2_zero [skip ci]
2026-06-08 chore: OTA index → v20260608-0816-esp32h2_zero-debug [skip ci]
2026-06-08 chore: OTA index → v20260608-0833-esp32h2_zero [skip ci]
2026-06-08 chore: OTA index → v20260608-0833-esp32h2_zero-debug [skip ci]
2026-06-08 chore: OTA index → v20260608-2038-esp32h2_zero-debug [skip ci]
2026-06-08 chore: OTA index → v20260608-2038-esp32h2_zero [skip ci]
2026-06-09 chore: OTA index → v20260609-1133-esp32h2_zero-debug [skip ci]
2026-06-09 chore: OTA index → v20260609-1133-esp32h2_zero [skip ci]
2026-06-09 chore: OTA index → v20260609-1244-esp32h2_zero-debug [skip ci]
2026-06-09 chore: OTA index → v20260609-1244-esp32h2_zero [skip ci]
2026-06-10 fix wiring
2026-06-18 chore: OTA index → v20260618-1817-esp32h2_zero-debug [skip ci]
2026-06-18 chore: OTA index → v20260618-1817-esp32h2_zero [skip ci]
2026-06-18 Revert "chore: OTA index → v20260618-1817-esp32h2_zero [skip ci]"
    This reverts commit 06a6ca736d2bd4943aba3d8576db101801ba6a84.
2026-06-18 Revert "chore: OTA index → v20260618-1817-esp32h2_zero-debug [skip ci]"
    This reverts commit c6d721d00372f93f90b8f07990ae85104ced4532.
2026-06-18 chore: OTA index → v20260618-1937-esp32h2_zero-debug [skip ci]
2026-06-18 chore: OTA index → v20260618-1937-esp32h2_zero [skip ci]
2026-06-18 chore: OTA index → v20260618-2011-esp32h2_zero-debug [skip ci]
2026-06-18 chore: OTA index → v20260618-2011-esp32h2_zero [skip ci]
2026-06-18 chore: OTA index → v20260618-2109-esp32h2_zero-debug [skip ci]
2026-06-18 chore: OTA index → v20260618-2109-esp32h2_zero [skip ci]
2026-06-19 chore: OTA index → v20260619-0635-esp32h2_zero-debug [skip ci]
2026-06-19 chore: OTA index → v20260619-0635-esp32h2_zero [skip ci]
2026-06-19 chore: OTA index → v20260619-1553-esp32h2_zero-debug [skip ci]
2026-06-19 chore: OTA index → v20260619-1553-esp32h2_zero [skip ci]
2026-06-20 chore: OTA index → v20260620-0659-esp32h2_zero-debug [skip ci]
2026-06-20 chore: OTA index → v20260620-0659-esp32h2_zero [skip ci]
2026-07-07 chore: OTA index → v20260707-2134-esp32h2_zero-debug [skip ci]
2026-07-07 chore: OTA index → v20260707-2134-esp32h2_zero [skip ci]
